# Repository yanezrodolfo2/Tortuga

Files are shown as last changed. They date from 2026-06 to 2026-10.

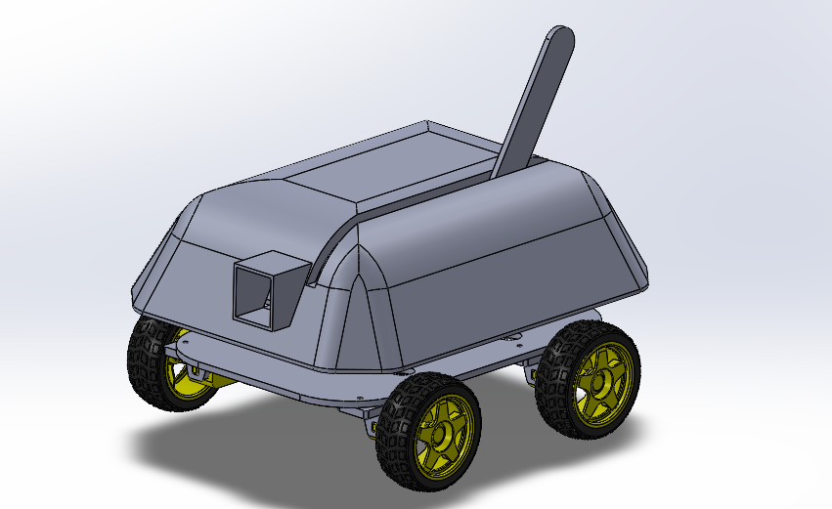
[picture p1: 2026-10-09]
media/assembly/Assembly.png

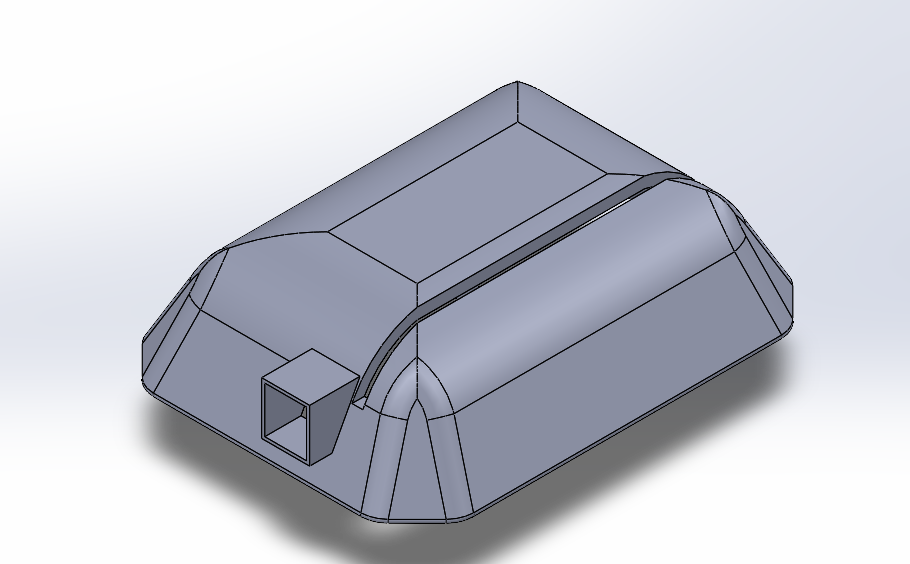
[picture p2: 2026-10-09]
media/cad_renders/v6/Shell.png

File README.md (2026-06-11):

# Tortuga

A self-righting, dust-tolerant scout rover. Mechanical engineering portfolio project.

**Built by:** Rodolfo Yanez — Mechanical Engineering, University of Arizona
**Status:** Phase 1 — chassis CAD complete, electronics integration next
**Timeline:** Summer 2026

---

## What problem does this solve?

Most student rovers are kit assemblies — they demonstrate integration, not engineering. Tortuga is built around two failure modes that have ended real Mars missions:

1. **Inversion.** A flipped rover is a dead rover without active recovery.
2. **Dust ingress.** Martian regolith degrades unsealed drivetrains.

The goal is not to replicate JPL hardware. The goal is to take JPL-class problems, scope them to hobby budget, and document the engineering decisions — at hobby scale, in the Sonoran Desert.

---

## Design highlights

- **Tortoise-shell chassis** — asymmetric rounded outline reduces catch points during inversion
- **Self-righting mechanism** — single servo-driven arm, IMU-triggered recovery
- **Sealed drivetrain** — labyrinth seals + sealed bearings for desert operation
- **SolidWorks parametric CAD** — every dimension is driven, fully editable
- **PETG construction** — survives Tucson summer heat (PLA would deform)

---

## Specs

| | |
|---|---|
| Footprint | 215mm × 160mm |
| Ground clearance | ~40mm |
| Drive | 4WD, TT gear motors, 80mm off-road wheels |
| Brain | Raspberry Pi 4 (4GB) |
| Sensors | HC-SR04 ultrasonic, MPU-6050 IMU, Pi Camera v2 |
| Power | 3x 18650 Li-ion |
| Target operating time | 45+ min continuous |

Full bill of materials in [`docs/bom.md`](docs/bom.md).

---

## Build phases

| Phase | What ships | Status |
|---|---|---|
| 1 | Drive + obstacle avoidance + camera stream | In progress |
| 1.5 | Self-righting + sealed drivetrain | Planned |
| 2 | Sonoran Desert field testing + dust analysis | Planned |
| 3 | GPS waypoint navigation, sample-collection gripper | Fall |

---

## Documentation

- [Engineering decision log](docs/decisions.md) — every non-trivial design choice and the reasoning behind it
- [Bill of materials](docs/bom.md) — components, sources, costs
- [Build schedule](docs/Rover_Project_Plan.docx) — 10-week project plan with milestones
- [CAD files](cad/) — SolidWorks source + STL exports, organized by subsystem

---

## Skills demonstrated

Mechanical design (SolidWorks) - Parametric CAD - 3D printing for functional parts - Statics applied to mechanism design - Electronics integration - Embedded Python - Technical documentation

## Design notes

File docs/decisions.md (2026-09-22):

# Engineering Decisions

Non-trivial design decisions for Tortuga, with reasoning and trade-offs. This log exists so I can defend every choice in an interview and so future-me remembers why. Trivial choices (filament color, exact tolerances, fastener brands) are omitted.

---

### Decision 1: Raspberry Pi over Arduino as primary controller
**Decision:** Raspberry Pi 4 (4GB). **Why:** Camera streaming and higher-level autonomy are roadmap items an Arduino can't do. The Pi handles both. **Trade-off:** Higher power draw, less deterministic timing than a microcontroller.

### Decision 2: PETG for final parts, PLA for prototypes
**Decision:** PETG for final structural parts; PLA for fit-check prototypes. **Why:** PLA softens above ~60°C — a Tucson car interior exceeds that. PETG (~75-80°C) survives desert heat. PLA is cheaper and more accurate for verifying fit before committing. **Trade-off:** PETG is harder to print clean and warps more on large flat parts.

### Decision 3: Self-righting via deployable arm, not symmetric chassis
**Decision:** Single servo-driven arm that levers the rover upright. **Why:** A symmetric operate-either-way chassis doubles every constraint — sensors, camera, wheels all needing to work inverted. An arm isolates the complexity to one mechanism. **Trade-off:** Single point of failure; if the servo or arm breaks, no recovery.

### Decision 4: Flip detection via IMU Z-axis with a dead band
**Decision:** MPU-6050 Z-axis acceleration determines orientation, with a ±5 m/s² dead band — above +5 upright, below −5 flipped, between is indeterminate. **Why:** Testing against zero causes rapid state flicker at steep angles, which would fire the arm repeatedly. The dead band forces a decisive orientation change. Sensor reads ~10-11 m/s² flat (offset from nominal 9.81 — common on cheap MPU-6050s) but sign-based detection is unaffected. **Trade-off:** Can't distinguish "on its side" from "mid-transition" — both handled as indeterminate.

### Decision 5: Chassis outline and dimensions
**Decision:** Base plate 230 × 180 × 4mm (enlarged from an initial 215 × 160), top deck 180 × 130 × 3mm, uniform 40mm corner fillets. **Why:** Enlarged so the body reads proportional to the 80mm wheels rather than dwarfed by them. Rounded outline reduces catch points during a flip. Front/rear defined by hole pattern, not shape, since the fillets are symmetric — the deck must be marked to avoid backwards assembly. **Trade-off:** 230mm is near the Prusa Core One's 240mm bed limit — prints with zero margin for error.

### Decision 6: Standoff span held constant across base plate redesigns
**Decision:** Kept the 6-standoff span at 140 × 50mm even when enlarging the base plate. **Why:** Holding the span constant means the existing top deck still fits any base plate revision — enlarging the plate doesn't cascade into a new deck. The standoffs just sit more central on a bigger plate. **Trade-off:** None meaningful; this is the move that kept a resize from becoming a full redesign.

### Decision 7: 4-corner motor layout, skid steer
**Decision:** Four TT motors in the corners, long axis along the rover's length, wheels on the long sides. No steering mechanism — turns by driving left and right sides at different speeds (skid steer). **Why:** Matches Mars rover wheelbase convention, maximizes 4WD traction, needs no steering linkage to break. **Trade-off:** Wheels scrub sideways in turns and it uses more power to turn than steered wheels.

### Decision 8: Motor bracket — sourced and adapted, not designed
**Decision:** Used a third-party 3D-printable TT motor bracket, modified to add mounting holes matching the base plate. **Why:** The TT motor's mounting holes sit on its top face at ~18-20mm spacing, which didn't match the plate's flat hole pattern. A proven bracket solves this without reinventing a standard part — time better spent on the parts that are actually mine. **Trade-off:** Not my original design; cited as adapted. The chassis, deck, camera bracket, righting arm, and servo mount are my designs.

### Decision 9: 80mm off-road wheels
**Decision:** 80mm chunky-tread rubber wheels on the TT motors. **Why:** ~40mm ground clearance vs ~25mm on standard 65mm wheels — meaningful for desert terrain. Tread grips loose sand. Hub fits the D-shaft directly, no adapter. **Trade-off:** No encoders on TT motors, so no closed-loop speed control without a later add-on. High wheel-to-body ratio drove the chassis enlargement in Decision 5.

### Decision 10: CAD in SolidWorks
**Decision:** SolidWorks as the CAD environment. **Why:** Dominant in aerospace and defense (Lockheed, Northrop, Raytheon, Boeing, SpaceX) — every CAD hour doubles as career prep. Free through UA. **Trade-off:** Windows-only; version control handled through GitHub commits of the source files.

### Decision 11: Two-tier layout on standoffs
**Decision:** Heavy components (motors, battery, driver) on the base plate; brain and sensors (Pi, IMU, camera) on a top deck raised 35mm on standoffs. **Why:** Keeps center of mass low, which aids stability and self-righting. Separates power wiring from signal wiring. 35mm clears the Pi, battery, and L298N below. **Trade-off:** Off-the-shelf standoff height locks the deck spacing.

### Decision 12: Edge-mounted forward-facing camera on a separate bracket
**Decision:** Pi camera mounts vertically at the front edge via a dedicated L-bracket, looking forward down the rover's length. **Why:** Forward-facing matches real rover camera placement and gives a clear driving view. A separate bracket lets the camera mount iterate without reprinting the deck. Bracket orientation matters — mounting across two side-by-side holes would face the camera sideways, so it uses a dedicated hole placement to face forward. **Trade-off:** Extra part to print and align; the mount design took several revisions to fit the real camera's hole pattern.

### Decision 13: Fillet at bracket load joints
**Decision:** 4mm fillet where bracket bases meet vertical walls (camera bracket, servo mount). **Why:** Sharp inside corners concentrate stress — an impact on the vertical face during a flip loads that joint. A fillet spreads the load and improves print layer bonding across the transition. **Trade-off:** Negligible extra material.

### Decision 14: Servo power separated from the Pi
**Decision:** MG996R servo powered from the battery (via breadboard rails), never from the Pi's 5V pins — only the signal wire and a common ground connect to the Pi. **Why:** The servo's ~2.5A stall current would brown out or damage the Pi. **Trade-off:** More wiring; requires a shared-ground discipline that, if missed, makes the servo jitter.

### Decision 15: lgpio backend for stable servo control
**Decision:** Drive the servo through gpiozero's lgpio pin factory rather than the default. **Why:** The default software PWM jittered; lgpio's hardware-timed signal holds steady. Combined with charged cells, this resolved a persistent servo buzz. **Trade-off:** A faint residual hold-buzz remains, accepted because the servo only holds briefly during a flip — it sweeps in motion, where the buzz is irrelevant.

### Decision 16: Phased build, three-wave parts ordering
**Decision:** Build in phases (self-righting demo first, driving later), order parts in waves (compute and tools, then drivetrain and sensors after the chassis was verified, then future-phase parts). **Why:** Prioritizing the self-righting demo produces the strongest single portfolio artifact fastest. Ordering after chassis verification caps the cost of a design error. **Trade-off:** Slower overall; a blocked subsystem can idle work.

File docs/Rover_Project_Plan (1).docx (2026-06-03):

Mars-Analog Scout Rover

Project Plan & Build Schedule

Rodolfo Yanez | Mechanical Engineering, University of Arizona

# Mission Goal

Design, build, and field-test a self-righting, dust-tolerant scout rover as a single-semester portfolio project targeting mechanical and aerospace internships in the Mars / space robotics space.

The rover addresses two failure modes that have ended real Mars missions:

- Loss of mobility from chassis inversion. A flipped rover is a dead rover without active recovery. Smaller scout-class rovers cannot rely on the wide, low geometry that protects Curiosity and Perseverance.
- Dust ingress into drivetrain components. Martian regolith is electrostatically charged and abrasive; Spirit's wheel actuators degraded from dust exposure. Most hobby rovers ignore this entirely.

The goal is not to replicate JPL hardware. The goal is to take JPL-class problems, scope them to hobby budget and timeline, and document the engineering decisions made along the way - the part recruiters actually care about.

## Measurable Design Goals

# | Goal | Target

1 | Autonomous obstacle avoidance | No collision over 5-min run
2 | Live camera stream | <500 ms latency, 480p min
3 | Self-right from any inverted orientation | 100% success over 10 trials
4 | Sealed drivetrain | 2+ hrs in desert sand, no degradation
5 | Thermal tolerance | Operate in 95F+ ambient
6 | Battery life | >= 45 min continuous drive

# Bill of Materials

Phase 1 + Phase 1.5 estimated cost. Final list will be locked in after CAD is complete and motor sizing is confirmed. All electronics sourced from Amazon, Adafruit, or SparkFun - never general hardware stores.

Subsystem | Component | Source | Cost
Compute | Raspberry Pi 4 (4GB) | Adafruit | $55
Compute | 32GB microSD card | Amazon | $10
Drive | TT gear motors x4 + wheels | Amazon | $15
Drive | L298N motor driver | Amazon | $8
Drive | Sealed bearings 608ZZ x8 | Amazon | $10
Sensing | HC-SR04 ultrasonic x3 | Amazon | $10
Sensing | Pi Camera Module v2 | Adafruit | $25
Sensing | MPU-6050 IMU | Amazon | $5
Power | 18650 cells x3 + holder | Amazon | $20
Power | TP4056 charger module | Amazon | $5
Power | 5V buck converter | Amazon | $8
Mechanism | MG996R servo (righting arm) | Amazon | $8
Hardware | M3 screws, standoffs, jumpers | Amazon | $30
Hardware | PETG filament | UA printer | $20
TOTAL | Phase 1 + 1.5 estimate | | ~$229

Total project budget: $300 - $500. ~$229 in Phase 1 + 1.5 components leaves headroom for failures (expect to lose 1-2 components as a first-time builder) and Phase 2 GPS hardware.

# Build Schedule (10 Weeks)

Phased plan. Each phase produces a working, demoable milestone - not a half-finished system. The rover drives before it self-rights; it self-rights before it goes to the desert.

Phase 1: Drive + Perceive | Phase 1.5: Differentiators | Phase 2: Field Testing | Phase 3: Future

Task | W1 | W2 | W3 | W4 | W5 | W6 | W7 | W8 | W9 | W10
Write README + plan repo
CAD chassis + righting arm
CoM + torque calculations
Order parts
Wire & breadboard test
Assemble drive base
Obstacle avoidance code
Camera streaming
Self-righting mechanism
Sealed drivetrain integration
IMU + recovery logic
Field testing (desert)
Documentation + writeup

## Phase Milestones

Phase 1 (Weeks 1-5) - Drive and perceive

- Chassis CAD complete and 3D printed
- 4-wheel drive functional under remote control
- Ultrasonic obstacle avoidance working
- Raspberry Pi camera streaming over local network
- Milestone: rover drives itself around an indoor course without collisions

Phase 1.5 (Weeks 6-8) - The differentiators

- Self-righting mechanism integrated and tuned
- Sealed drivetrain components installed (labyrinth seals, sealed bearings)
- IMU-triggered recovery sequence working
- Milestone: rover recovers from forced flips in lab conditions

Phase 2 (Weeks 9-10) - Field testing

- Outdoor testing in Sonoran Desert terrain
- Dust exposure protocol: run, disassemble, document wear
- Before/after photos and writeup of drivetrain components
- Milestone: documented test results showing seal performance

Phase 3 (Post-semester) - Future expansion

- GPS waypoint navigation
- Possible sample-collection gripper (Mars Sample Return inspired)

# Known Risks

- First electronics project. Expect to fry 1-2 components from wrong polarity or voltage. Build environment with this in mind; do not solder anything permanent until breadboard tests pass.
- Self-righting mechanism is a single point of failure. If the servo or linkage breaks, recovery fails. Backup plan: test mechanism in isolation before integrating with the rover.
- PETG prints are harder than PLA. First seal housings may need multiple iterations. Build time buffer into the CAD weeks.
- Desert testing is weather and schedule dependent. Phase 2 needs a backup indoor protocol if field tests slip.

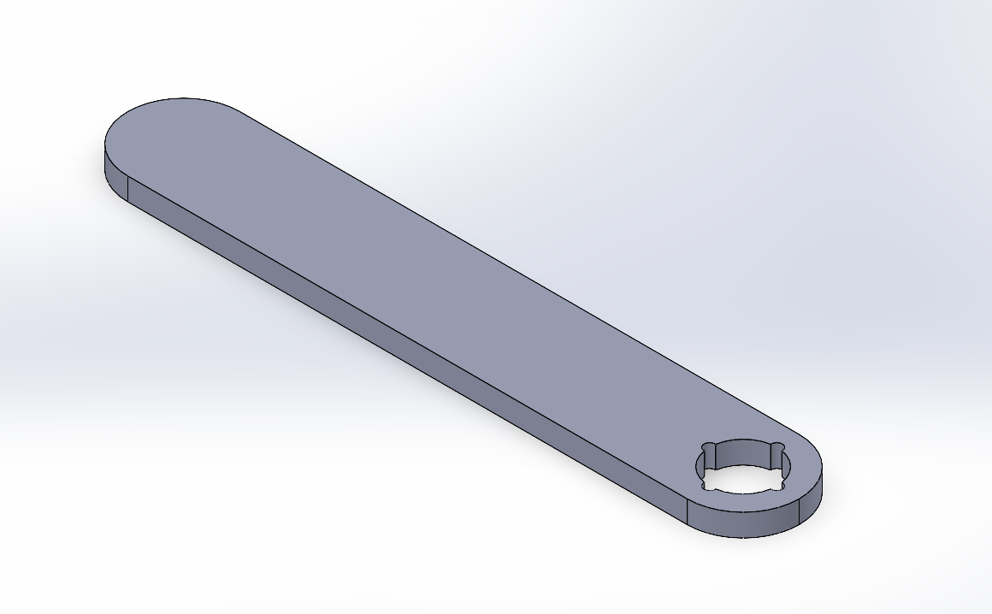
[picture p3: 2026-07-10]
media/cad_renders/Righting Arm v4.png

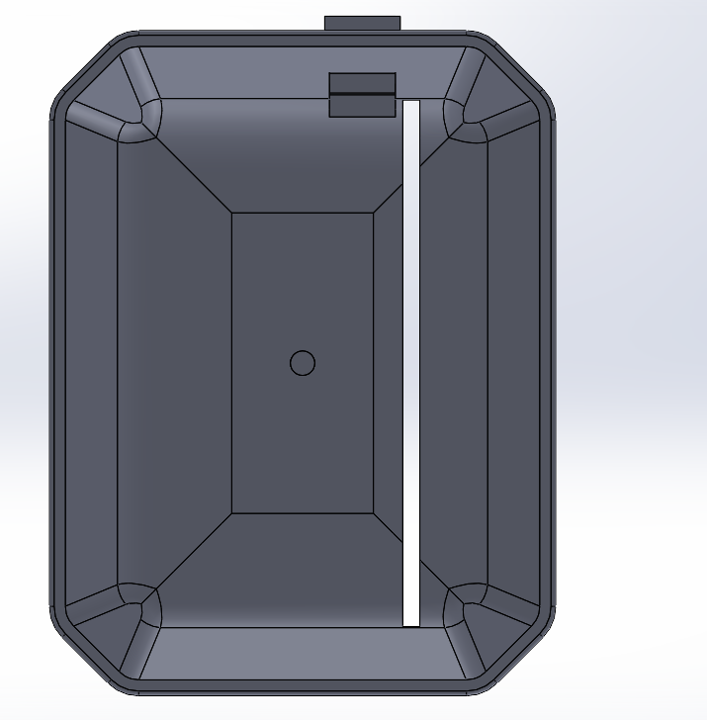
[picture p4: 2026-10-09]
media/cad_renders/v6/Shell Bottom.png

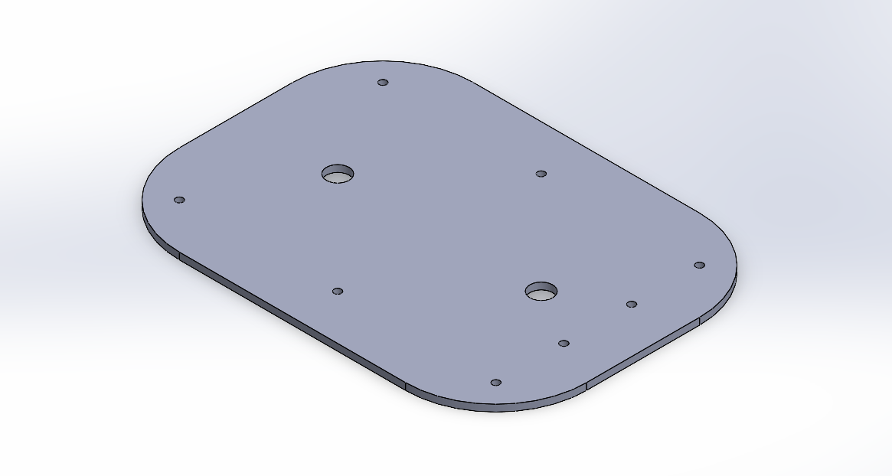
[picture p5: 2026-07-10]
media/cad_renders/Top Deck v4.png

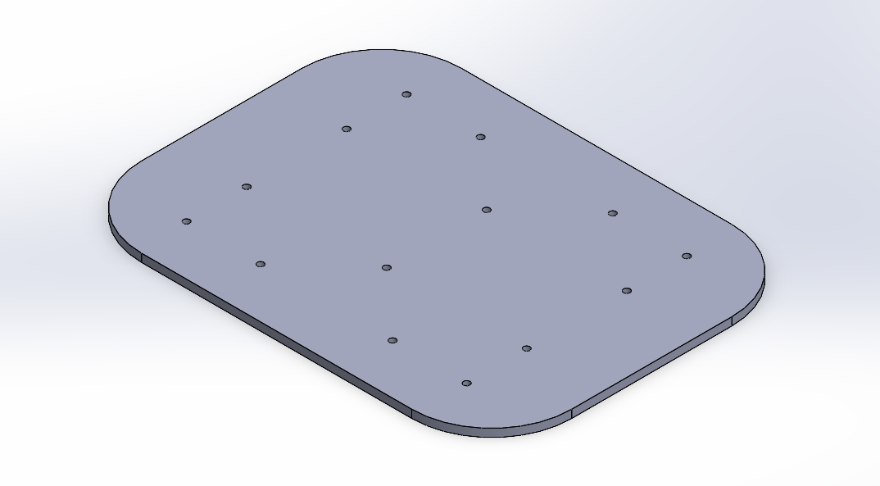
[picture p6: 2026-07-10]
media/cad_renders/Base Plate v4.png

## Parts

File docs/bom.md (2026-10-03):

# Bill of Materials

Estimated Phase 1 + 1.5 component costs. Final list locked in at end of CAD phase. All electronics sourced from Amazon, Adafruit, or SparkFun — never general hardware stores. Hardware (screws, standoffs) and tools sourced locally where convenient.

---

## Phase 1 + 1.5 components

| Subsystem | Component | Source | Est. Cost |
|---|---|---|---|
| Compute | Raspberry Pi 4 (4GB) | Adafruit | $55 |
| Compute | 32GB microSD card | Amazon | $10 |
| Drive | TT gear motors ×4 + wheels | Amazon | $15 |
| Drive | L298N motor driver | Amazon | $8 |
| Drive | 80mm off-road rubber wheels ×4 | Amazon | $12 |
| Drive | Sealed bearings 608ZZ ×8 | Amazon | $10 |
| Sensing | HC-SR04 ultrasonic ×3 | Amazon | $10 |
| Sensing | Pi Camera Module v2 | Adafruit | $25 |
| Sensing | MPU-6050 IMU | Amazon | $5 |
| Power | 18650 cells ×3 + holder | Amazon | $20 |
| Power | TP4056 charger module | Amazon | $5 |
| Power | 5V buck converter | Amazon | $8 |
| Mechanism | MG996R servo (righting arm) | Amazon | $8 |
| Hardware | M3 standoffs kit (35mm + assorted) | Amazon | $15 |
| Hardware | M3 screws, nuts, washers | Amazon | $15 |
| Hardware | Jumper wires + breadboard | Amazon | $10 |
| Hardware | PETG filament (1kg) | UA makerspace | $20 |
| **Total Phase 1 + 1.5** | | | **~$251** |

---

## Phase 2 (field testing)

| Component | Source | Est. Cost |
|---|---|---|
| Spare batteries + chargers | Amazon | $15 |
| Replacement parts buffer | Amazon | $30 |
| Field photography setup (phone tripod) | Amazon | $20 |
| **Phase 2 total** | | **~$65** |

---

## Phase 3 (post-semester — future)

| Component | Source | Est. Cost |
|---|---|---|
| GPS module (NEO-6M or similar) | Amazon | $15 |
| Servo + linkage for sample gripper | Amazon | $25 |
| Magnetic encoders (TT motor add-on) | Amazon | $10 |
| **Phase 3 total** | | **~$50** |

---

## Project budget summary

| Phase | Estimate |
|---|---|
| Phase 1 + 1.5 | $251 |
| Phase 2 buffer | $65 |
| Phase 3 (future) | $50 |
| **Total project envelope** | **~$366** |

Project budget cap: $300–$500. Phase 1 + 1.5 alone fits within budget with ~$50 cushion for failed components (expected to lose 1–2 parts as a first-time builder). Phase 3 is post-semester scope and not part of the initial budget.

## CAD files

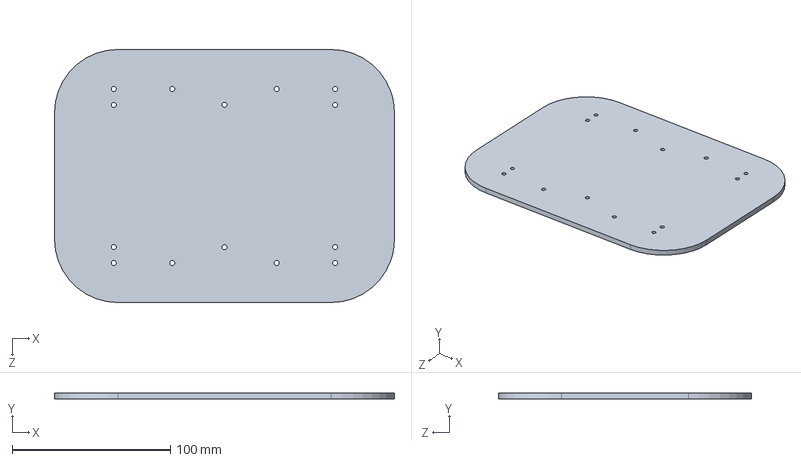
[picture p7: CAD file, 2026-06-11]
cad/base_plate/Tortuga_BasePlate_v3.SLDPRT
215.0 x 4.00 x 160.0 mm

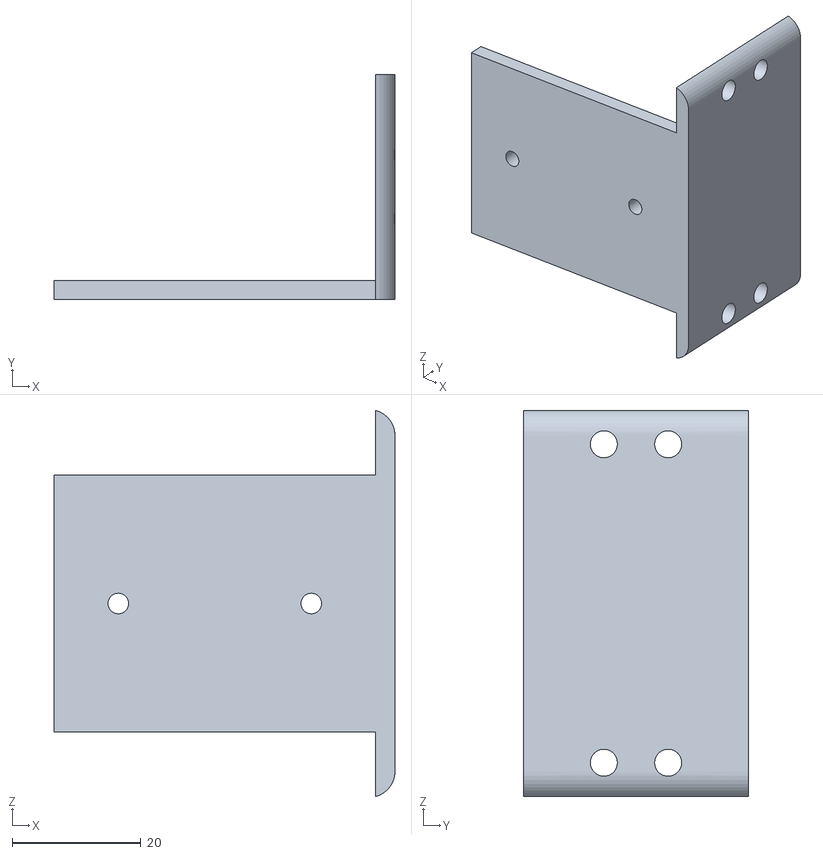
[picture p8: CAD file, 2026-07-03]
cad/r_arm/Tortuga_ServoMount_v1.STL
53.0 x 35.0 x 60.0

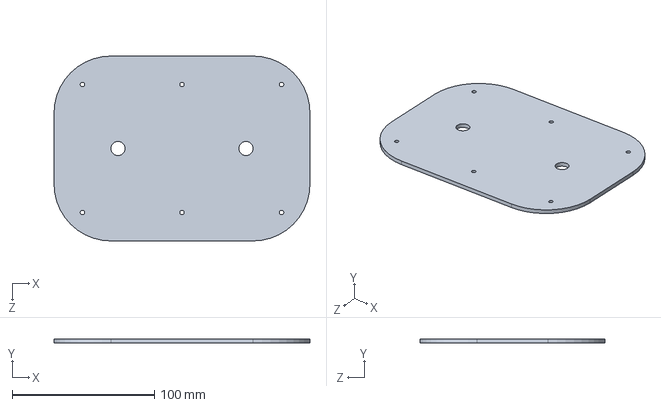
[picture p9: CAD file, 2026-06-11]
cad/top_deck/Tortuga_TopDeck_v1.SLDPRT
180.0 x 3.00 x 130.0 mm

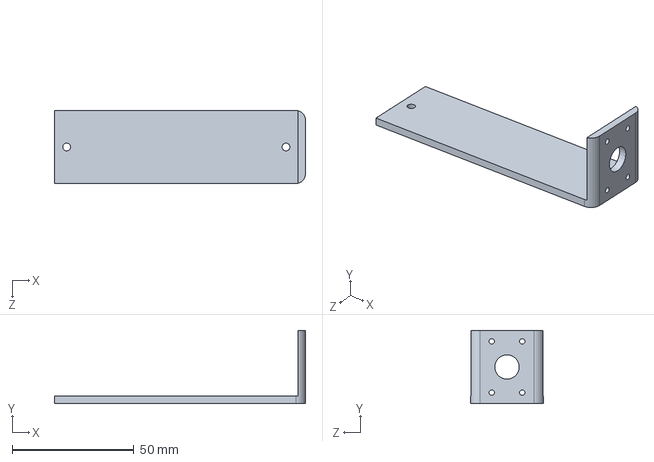
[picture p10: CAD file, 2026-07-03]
cad/cam_bracket/Tortuga_CamBracket_v2.SLDPRT
103.0 x 30.0 x 30.0 mm

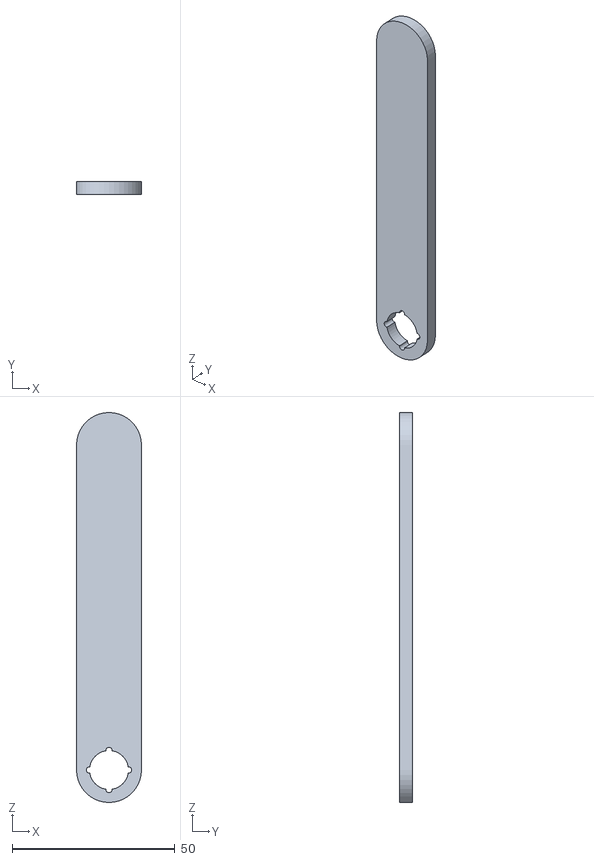
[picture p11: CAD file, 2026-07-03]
cad/r_arm/Tortuga_RightingArm_v1.STL
20.0 x 4.00 x 120.0

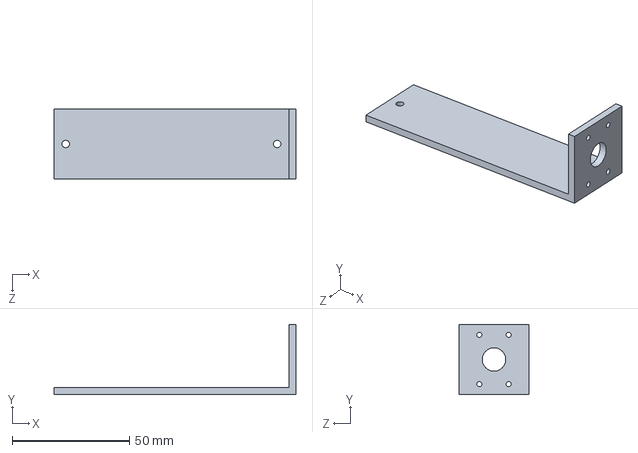
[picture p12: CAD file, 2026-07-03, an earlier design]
cad/cam_bracket/Tortuga_CamBracket_v1.SLDPRT
103.0 x 30.0 x 30.0 mm

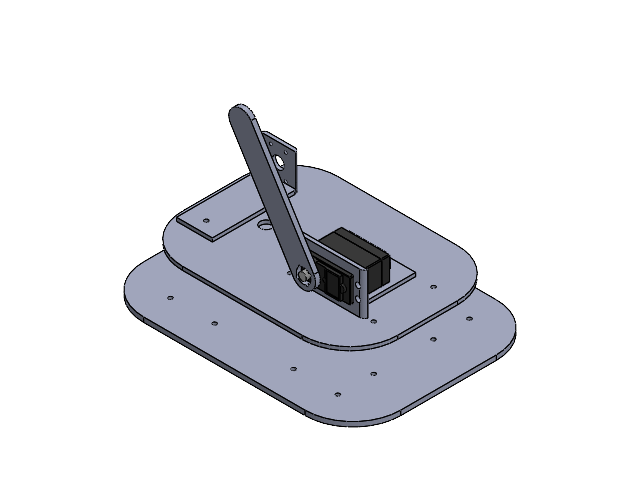
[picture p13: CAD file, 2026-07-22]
cad/assemblies/Asembly.SLDASM
Tortuga_BasePlate_v4
Tortuga_TopDeck_v5
Tortuga_ServoMount_v4
Tortuga_CamBracket_v5
Servo Motor Model(MG996R)
Tortuga_RightingArm_v4

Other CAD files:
cad/base_plate/Tortuga_BasePlate_v3.STL
cad/cam_bracket/Tortuga_CamBracket_v1.STL
cad/cam_bracket/Tortuga_CamBracket_v2.STL
cad/top_deck/Tortuga_TopDeck_v1.STL

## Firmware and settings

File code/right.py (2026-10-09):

"""
right.py - Tortuga self-righting routine

Purpose:
    The integrated self-righting program. Continuously reads the
    MPU-6050 Z axis; when the rover is detected inverted, it drives
    the righting arm from stowed to deployed, holds, then returns the
    arm to stowed and waits before re-arming.

Sequence:
    1. Arm driven to STOWED on startup, held 1 s to settle.
    2. Loop: read Z.
         z < -5 m/s^2  -> inverted. Deploy arm, hold 1.5 s so the
                          sweep carries the chassis over, return to
                          STOWED, then wait 3 s before testing again
                          (prevents immediate re-trigger while the
                          rover is still settling).
         otherwise     -> upright, print Z and keep watching.
    3. 0.3 s poll interval.

Servo positions:
    STOWED   = -0.4   arm lies along the deck
    DEPLOYED = +0.8   arm swept out past vertical

    DEPLOYED was raised from +0.4 to +0.8 during bench testing: at
    +0.4 the arm swept but did not carry enough angle to roll the
    assembled chassis over.

Wiring:
    MPU-6050: VCC -> pin 1, GND -> pin 6, SDA -> pin 3, SCL -> pin 5
    MG996R:   signal (orange) -> GPIO 12 (physical pin 32)
              power  (red)    -> 7.4V battery +
              ground (brown)  -> battery -, jumpered to Pi GND (pin 6)

Prerequisites:
    pip install mpu6050-raspberrypi --break-system-packages
    sudo apt install i2c-tools python3-smbus python3-lgpio
    I2C enabled via raspi-config; verify with: i2cdetect -y 1 -> 0x68

Run:
    python3 right.py
    Ctrl+C to exit.
"""

from gpiozero import Servo, Device
from gpiozero.pins.lgpio import LGPIOFactory
from mpu6050 import mpu6050
from time import sleep

Device.pin_factory = LGPIOFactory()

sensor = mpu6050(0x68)
s = Servo(12, min_pulse_width=0.0006, max_pulse_width=0.0024)

STOWED = -0.4
DEPLOYED = 0.8

s.value = STOWED
sleep(1)

print("watching for flip...")

while True:
    z = sensor.get_accel_data()['z']

    if z < -5:
        print("FLIPPED - deploying arm")
        s.value = DEPLOYED
        sleep(1.5)
        s.value = STOWED
        sleep(3)
    else:
        print(f"upright  z={z:.1f}")

    sleep(0.3)

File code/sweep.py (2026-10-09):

"""
sweep.py - MG996R servo range test

Purpose:
    Sweeps the righting-arm servo between its stowed and deployed
    positions on a loop, with no sensor in the path. Used to verify
    travel, check for mechanical interference with the shell, and
    confirm the arm clears the chassis before the detection logic is
    connected.

Why LGPIOFactory:
    gpiozero's default pin factory generates PWM in software, which
    produced visible jitter and audible buzzing on the MG996R. Setting
    the pin factory to lgpio moves PWM generation to hardware timing
    and the jitter largely disappears. (pigpio would also work but has
    no installation candidate on the current Raspberry Pi OS release.)

Pulse widths:
    min_pulse_width=0.0006 (600 us), max_pulse_width=0.0024 (2400 us)
    These override gpiozero's 1000-2000 us default to match the
    MG996R's actual range, so s.value = -1..+1 maps to the full sweep.

Wiring (MG996R):
    Signal (orange) -> Pi GPIO 12 (physical pin 32)
    Power  (red)    -> battery + (7.4V pack, NOT the Pi's 5V rail -
                       the MG996R draws up to ~2.5A at stall)
    Ground (brown)  -> battery -, AND jumpered to Pi GND (pin 6)
                       Grounds must be tied common for the signal to
                       have a reference.

Prerequisites:
    sudo apt install python3-lgpio

Run:
    python3 sweep.py
    Ctrl+C to exit.
"""

from gpiozero import Servo, Device
from gpiozero.pins.lgpio import LGPIOFactory
from time import sleep

Device.pin_factory = LGPIOFactory()

s = Servo(12, min_pulse_width=0.0006, max_pulse_width=0.0024)

while True:
    s.value = -0.4
    sleep(1)
    s.value = 0.4
    sleep(1)
